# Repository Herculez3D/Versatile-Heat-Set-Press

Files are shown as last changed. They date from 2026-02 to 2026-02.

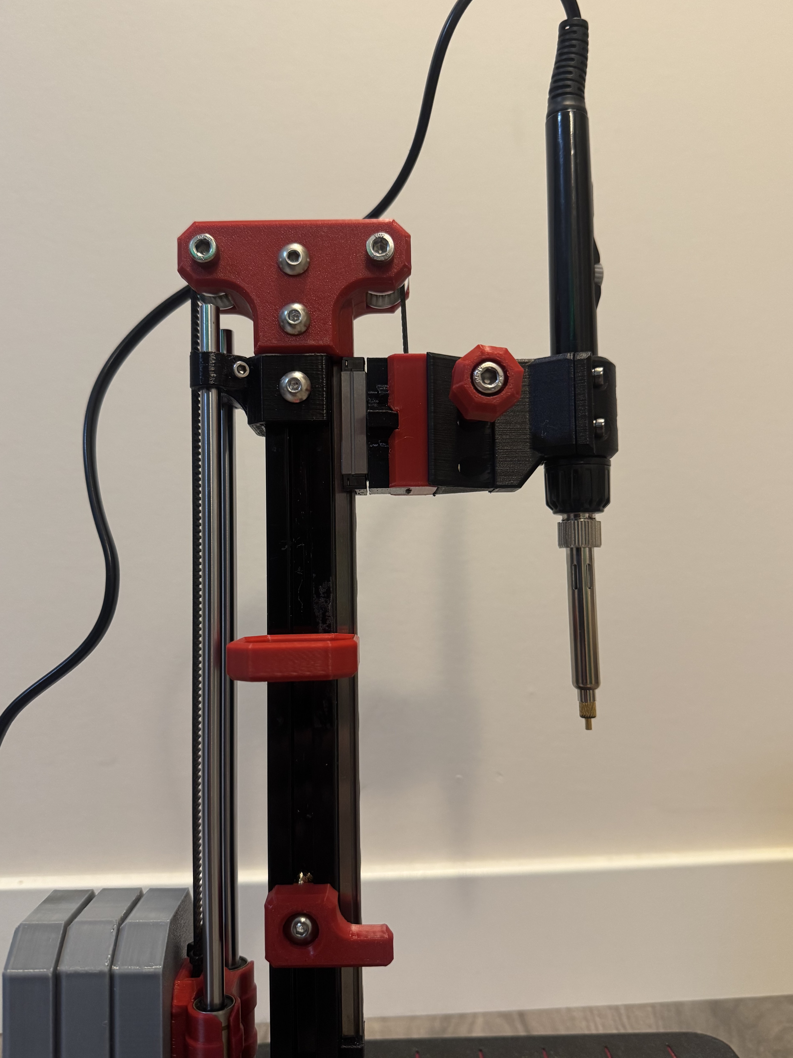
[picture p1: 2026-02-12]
Gallery/Upper Assembly.jpeg

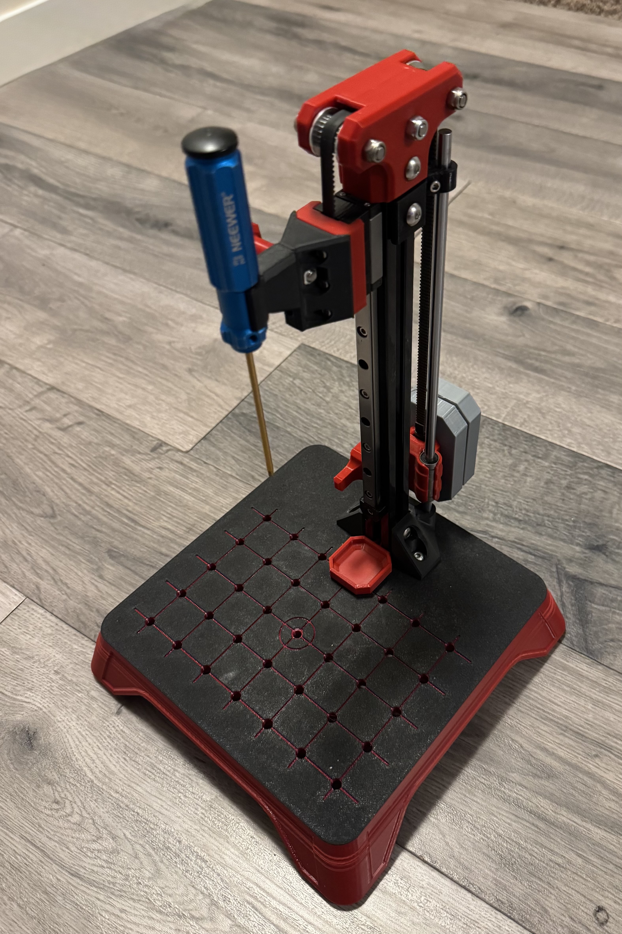
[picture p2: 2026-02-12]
Gallery/IMG_3691.jpeg

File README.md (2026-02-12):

# 🛠 Versatile Heat Seat Press (MGN9 Based)

A mostly 3D-printed, modular heat-set press built to live on your desk — and do more than just press inserts.

This started as “I need a better way to install heat-set inserts.”  
It turned into a small, milling-machine-inspired vertical platform that can grow into whatever you want it to be.

Want a heat-set press? Done.  
Want a mini drill press with a Dremel? Go for it.  
Want a precision vertical driver for starting threads? Easy.

The whole thing is designed to be **modular, hackable, and expandable.**

✅ Ender 3 compatible (235mm x 235mm build volume)

---

Main Cad

---

# 🚧 Project Status

This is an **active, evolving project.**

New parts and refinements are being added as I iterate.  
Assembly documentation is still in progress — for now, the Fusion 360 file is the best reference for hardware placement.

If you build one or improve something, I’d genuinely love to see it.

---

# 📢 Latest Updates (2026-02-11)

- Added new fixture parts and accessory components  
- Added a **Blank Tool Mount** for custom tooling  
- Fixed base alignment issue (moved third bolt to rear to ensure perpendicular extrusion alignment)  
- Added **Mini Tombstones** (hold ~10 Canadian dimes — currently testing)

---

# 🎯 Features

## 🧱 Fixture Plate Base
25mm grid layout with M5 mounting points allows you to:
- Design custom jigs  
- Add hard stops  
- Mount angle plates  
- Create repeatable setups  

Built to be expanded — not just used once.

---

## 🚂 MGN9 Linear Rail
- 200mm MGN9 rail  
- MGN9H carriage  

Smooth, rigid, controlled vertical motion.

---

## ⚖ Adjustable Counterweight System
Stackable “Tombstones” let you tune the feel of the press.

Fill options:
- Canadian nickels (15 tested per tombstone)
- Canadian dimes (mini version)
- Lead tire weights
- Steel stock
- Sand (pause print before top layers)
- Any dense material that fits

Weight cavity size must be smaller than:

`30mm (L) x 10mm (W) x 10mm (H)`

---

## 🔧 Modular Tooling System

- Blank tool mount included  
- Design your own tool posts  
- Mount rotary tools  
- Create specialty press heads  
- Build custom driver holders  

If you can model it, you can mount it.

---

# 📐 Specifications

- **Max Part Diameter:** 150mm  
- **Z Travel:** 155mm  
- **Bed Area:** 200mm x 150mm  
- **Printer Requirement:** 235mm x 235mm build plate  

---

# 🧰 Bill of Materials

## Frame & Motion
- 1x 300mm 2020 Aluminum Extrusion  
- 1x 200mm MGN9 Linear Rail  
- 1x MGN9H Linear Block  
- 2x 250mm 6mm Linear Rod  
- 2x LM6LUU Linear Bearings  
- 2x 20T 9mm GT2 Idlers (5mm ID)  
- ~400mm GT2 Belt (6mm or 9mm works)  
- 1x 3mm x 20mm Pin  

## M5 Hardware
- 2x M5 x45mm SHCS  
- 2x M5 x35mm SHCS (BHCS also works)  
- 14x M5 x10mm BHCS  
- 11x M5 T-Slot Nuts  
- 34x M5 Heat Set Inserts (7mm OD x 5mm long)  
- 4x M5 Hex Nuts  

## M3 Hardware
- 2x M3 x30mm SHCS  
- 10–20x M3 x15mm SHCS  
- 8x M3 x10mm SHCS  
- 11x M3 x8mm SHCS  
- 11x M3 T-Slot Nuts  
- 15–25x M3 Heat Set Inserts (Voron spec)  
- 2x M3 Square Nuts (2mm thick)  

## Misc
- Small zip ties  
- Heat-set insert tool  

---

# 🖨 Print Settings

## Standard Parts
- 0.2mm layer height  
- 0.4mm nozzle  
- 30% infill (Cubic recommended)  
- 3+ walls  
- 6+ top layers  
- 6+ bottom layers  
- No supports required  

## Recommended Materials
- PETG  
- ABS  
- ASA  
- TPU (for feet)  

PLA can be used for the base if necessary.

---

# 🧩 Print Notes

### Base
Large part — prone to warping.  
Ensure strong bed adhesion.

Optional: Manual filament swap at layer 3 for accent color.

### Tombstones
Use “Add Negative Part” in your slicer to create weight cavity.

Process:
1. Add cavity shape  
2. Add pause before bridge layer closes cavity  
3. Insert weights  
4. Resume print  

A Canadian nickel cavity model is included.

### Feet (x4)
Material: TPU  
- 2 walls  
- 3 bottom layers  
- 0 top layers  
- 25% hex infill  

### Tray (Optional)
Clips into extrusion.  
Convenient insert holder that stays out of the way.

---

# 🔩 Assembly

Assembly documentation coming soon.

For now:
- Reference the Fusion 360 file  
- Fasteners are shown in CAD  

---

# 🤝 Contributing

This project is meant to evolve.

If you:
- Design new tool mounts  
- Improve alignment  
- Create new fixture accessories  
- Optimize print strength  
- Expand travel  
- Improve documentation  

Open a PR or share your build.

---

# 💬 Final Notes

This press works great out of the box — but it was designed to grow with you.

Build it. Modify it. Improve it.

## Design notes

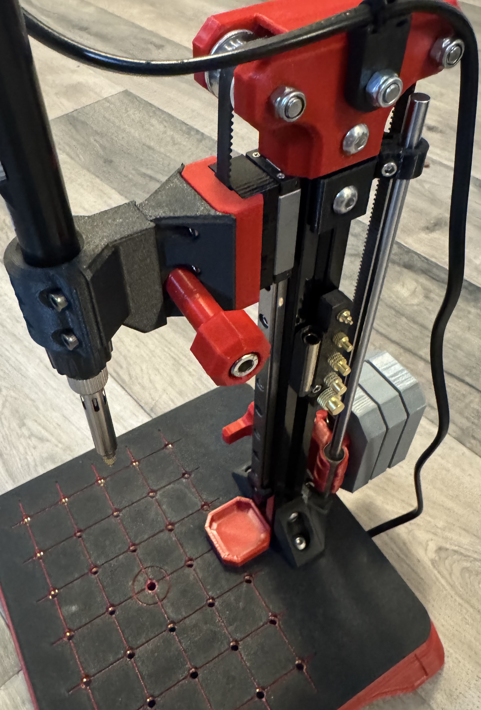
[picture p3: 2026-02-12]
Gallery/Right Side New.jpeg

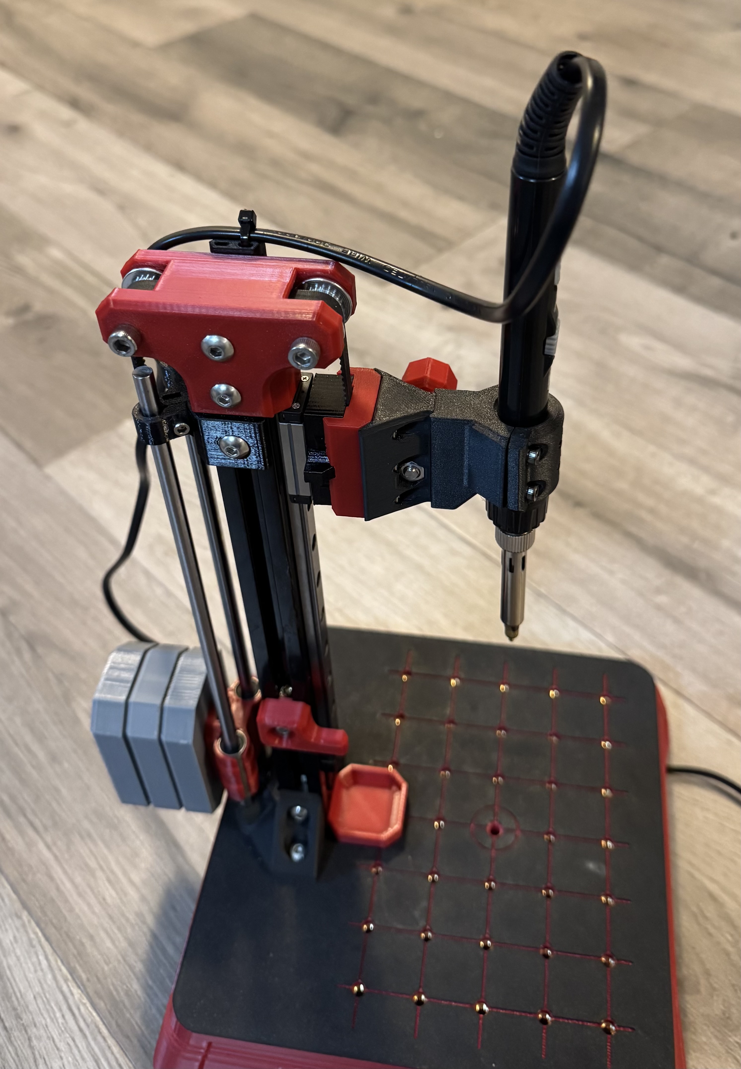
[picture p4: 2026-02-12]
Gallery/Left New.jpeg

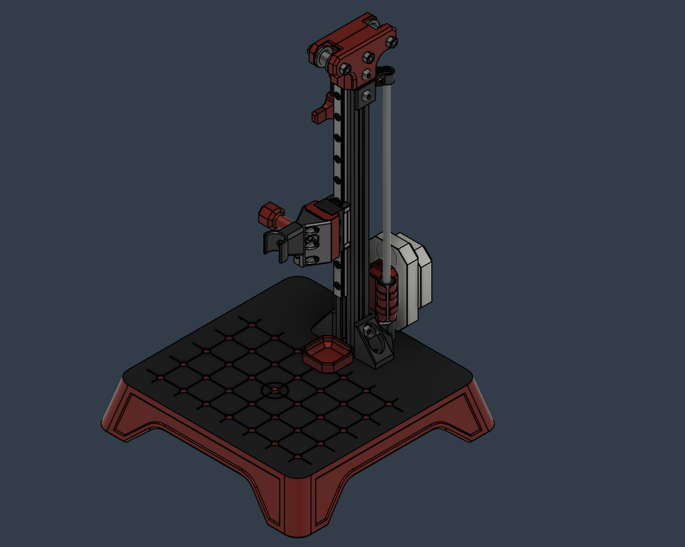
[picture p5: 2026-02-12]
Gallery/Screenshot (25).png

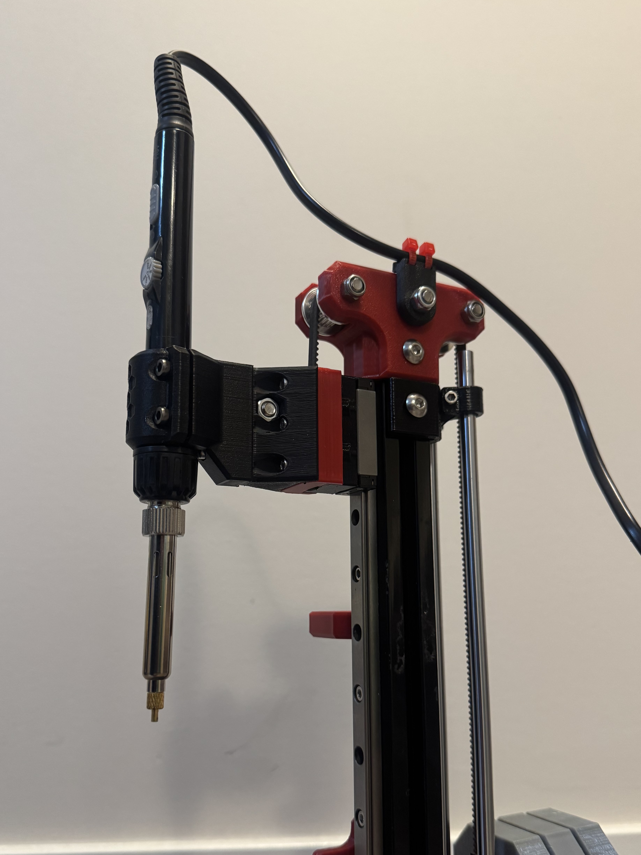
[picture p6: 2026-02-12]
Gallery/From under.jpeg

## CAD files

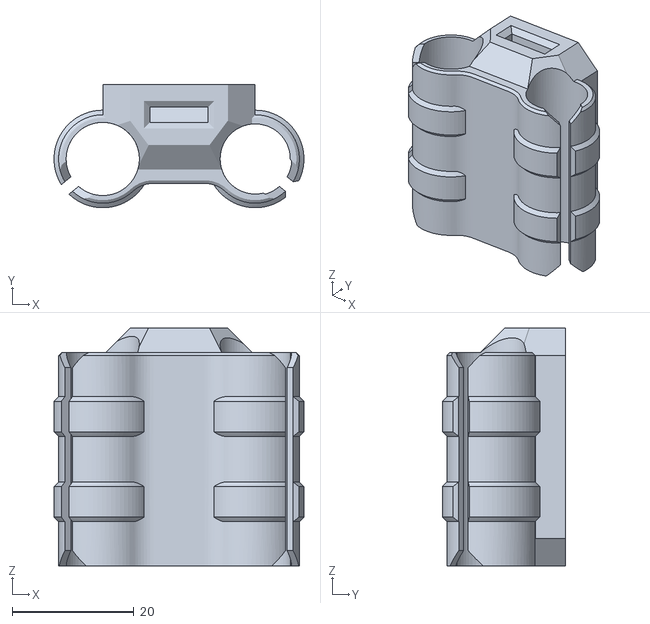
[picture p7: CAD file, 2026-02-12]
STL's/CounterWeight/Counterweight Carrier(a).stl
41.0 x 20.2 x 39.0

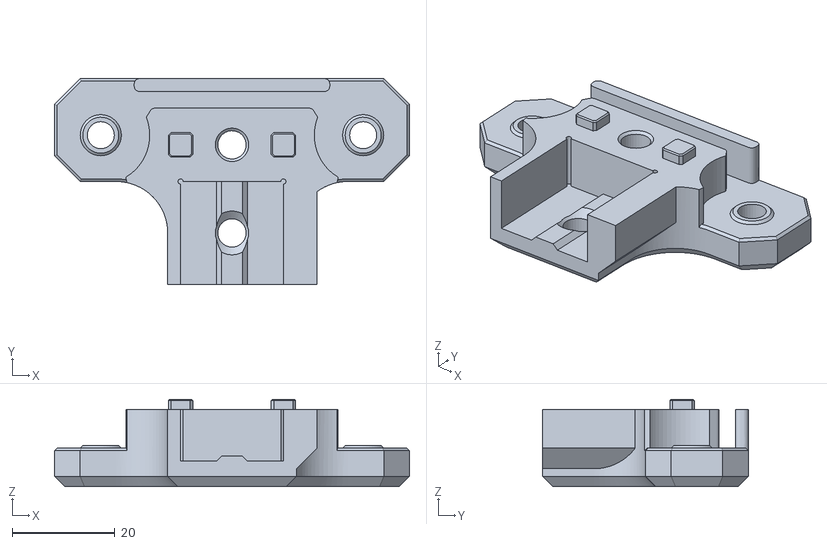
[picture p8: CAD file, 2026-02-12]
STL's/Frame/Pulley Block Right(a).stl
69.0 x 40.0 x 17.0

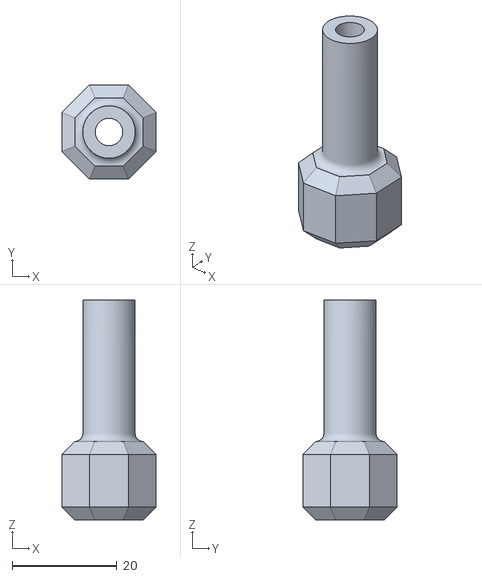
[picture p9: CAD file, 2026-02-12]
STL's/Tool Mounting/Knob(a).stl
18.0 x 18.0 x 42.0

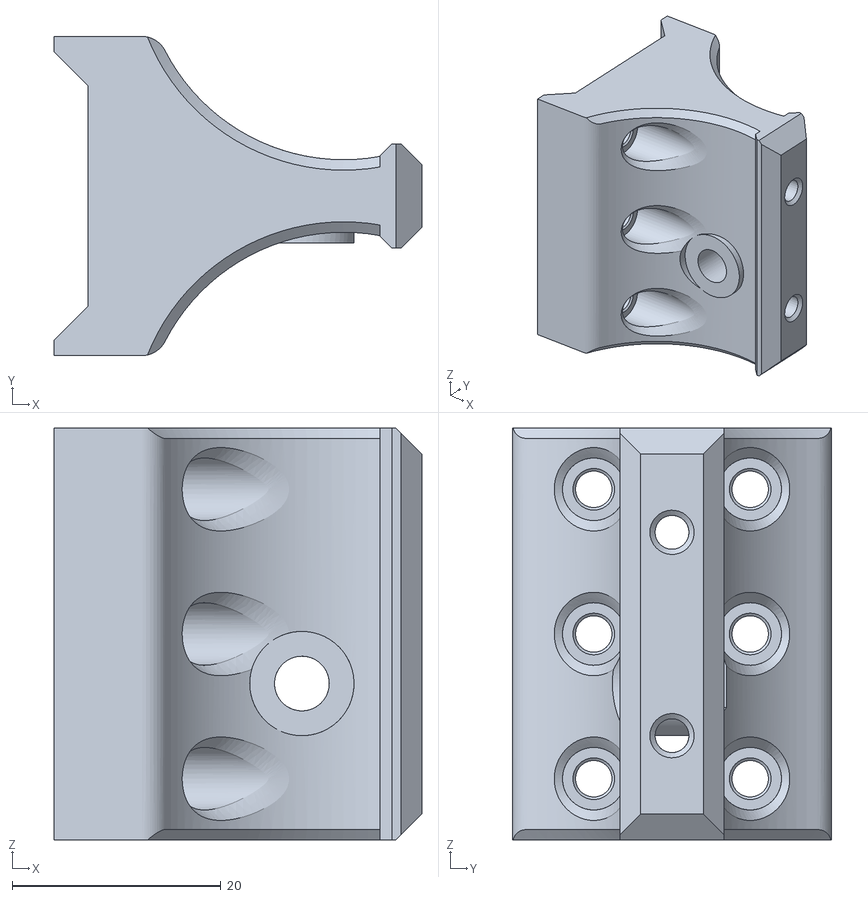
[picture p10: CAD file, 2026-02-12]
STL's/Tool Mounting/Long Tool Post/Tool Post Long.stl
35.2 x 30.6 x 39.5

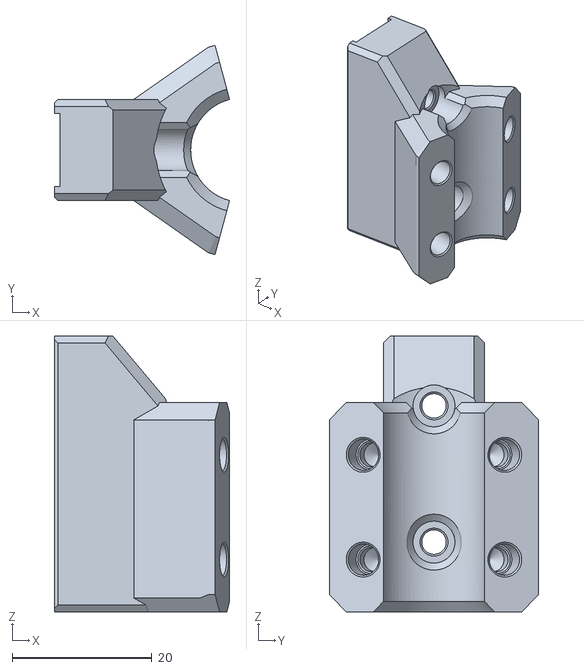
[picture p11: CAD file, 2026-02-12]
STL's/Tool Mounting/Short Tool Post/Amazon Heat Set Tool/Mount.stl
25.1 x 29.9 x 39.5

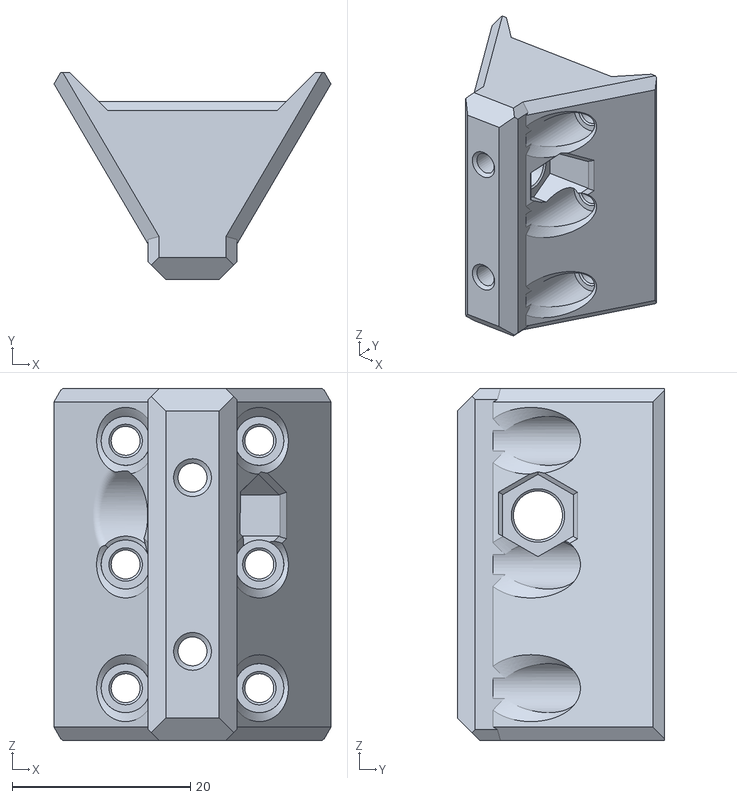
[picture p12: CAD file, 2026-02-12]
STL's/Tool Mounting/Short Tool Post/Tool Post Short.stl
31.1 x 23.3 x 39.5

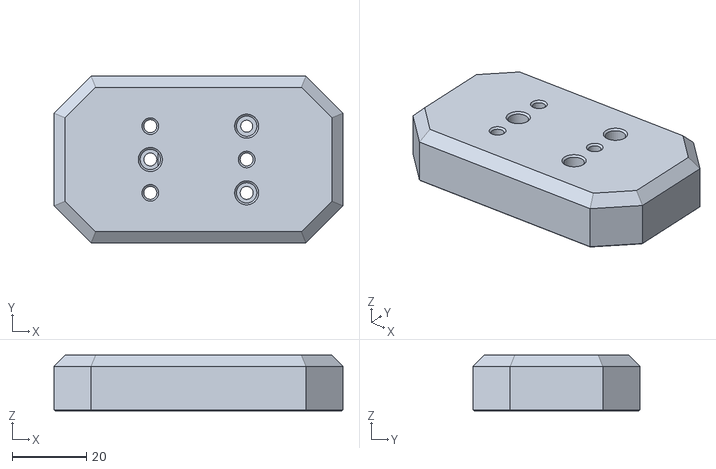
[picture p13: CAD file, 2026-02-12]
STL's/CounterWeight/Tombstone (Candian Nickel).stl
78.0 x 45.0 x 15.0

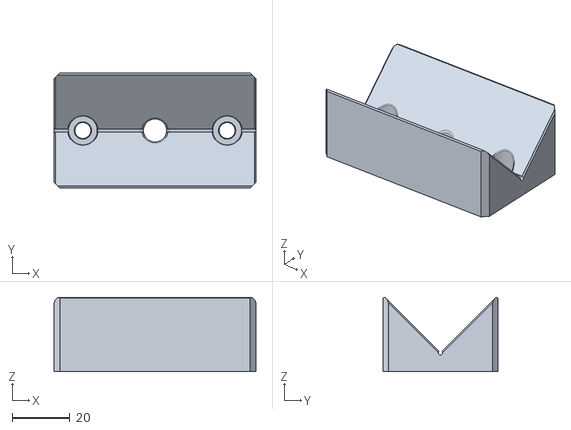
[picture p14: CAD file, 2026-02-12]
STL's/Fixtures/Vee Block.stl
70.0 x 40.0 x 25.8

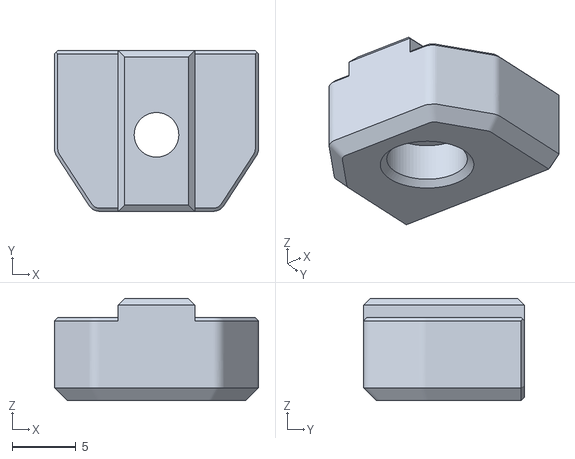
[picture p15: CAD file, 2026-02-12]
STL's/Frame/MGN9 Hard Stop.stl
16.0 x 12.6 x 8.00

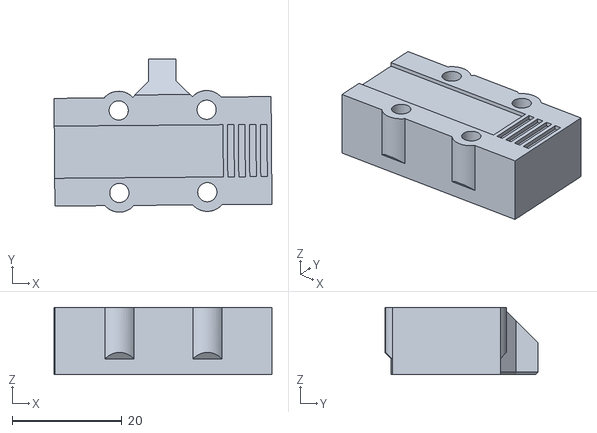
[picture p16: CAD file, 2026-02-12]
STL's/Tool Mounting/Belt Block.stl
39.7 x 27.9 x 12.3

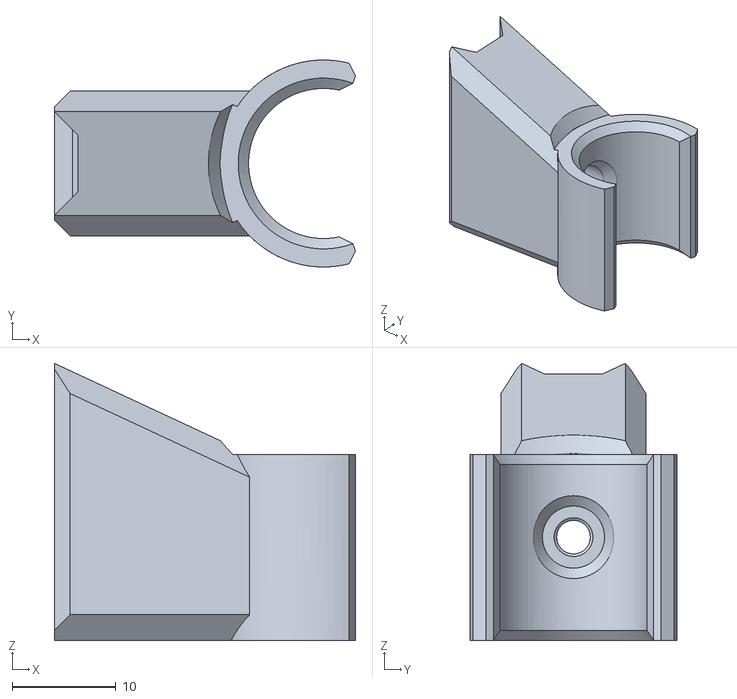
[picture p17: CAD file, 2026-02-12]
STL's/Tool Mounting/Short Tool Post/15mm Driver Holder.stl
29.1 x 20.0 x 26.8

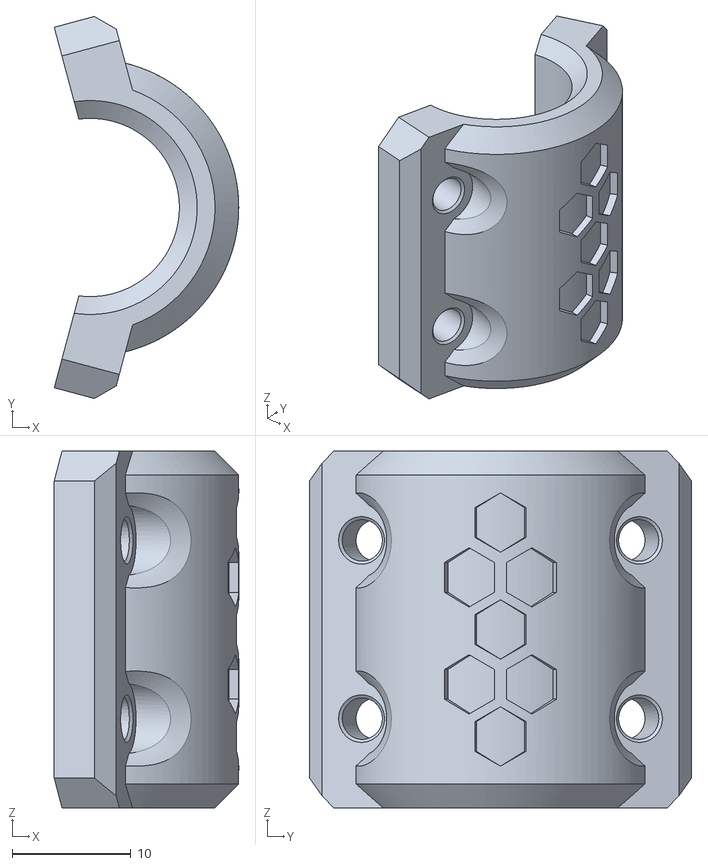
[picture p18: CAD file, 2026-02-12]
STL's/Tool Mounting/Short Tool Post/Amazon Heat Set Tool/Clamp.stl
15.5 x 32.1 x 30.0

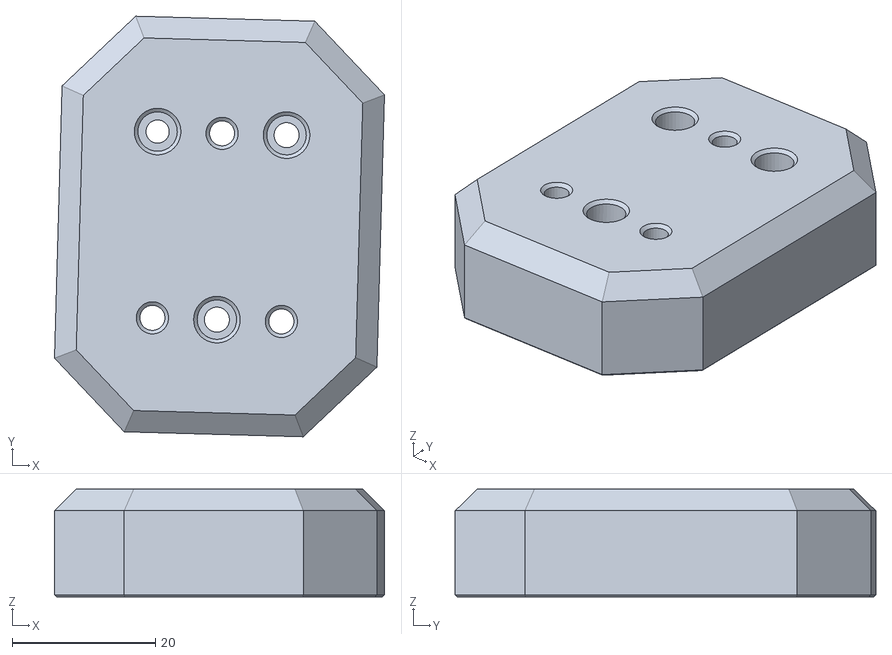
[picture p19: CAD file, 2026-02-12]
STL's/CounterWeight/MiniTombstone (Candian Dime).stl
46.0 x 58.7 x 15.0

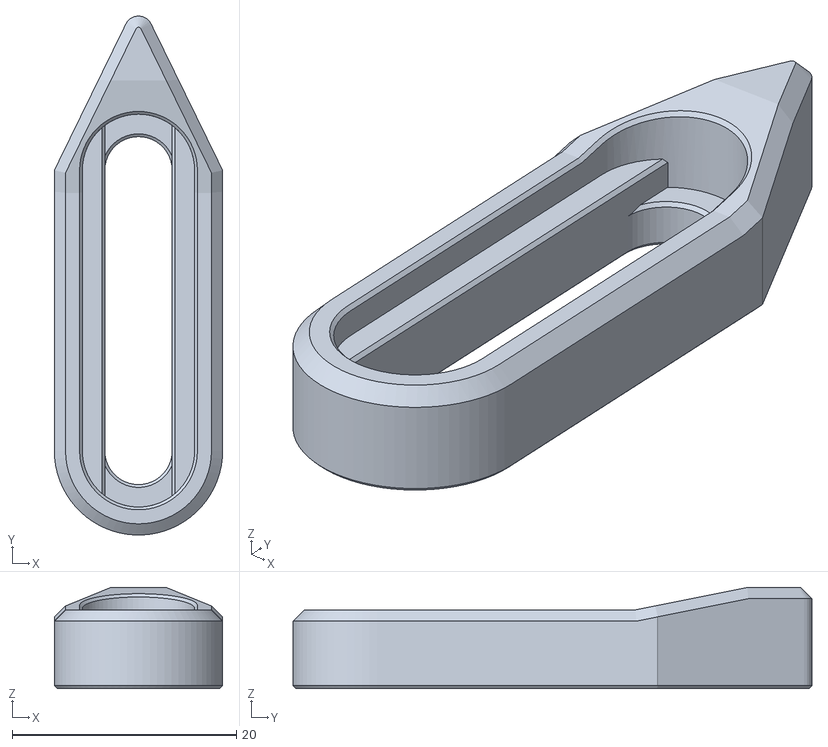
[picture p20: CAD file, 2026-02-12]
STL's/Fixtures/Pin Stop.stl
15.0 x 46.2 x 9.00

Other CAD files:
STL's/Frame/Bottom Brace.stl
STL's/Tool Mounting/Belt Clamp(a).stl
STL's/Tool Mounting/Short Tool Post/Amazon Heat Set Tool/Adapter Holder.stl
STL's/CounterWeight/Tombstone (solid).stl
STL's/Fixtures/Flat Stop.stl
STL's/Fixtures/Washer.stl
STL's/Frame/Adjustable Stop(a).stl
STL's/Frame/Base.stl
STL's/Frame/Cable Strain Relief.stl
STL's/Frame/Pulley Block Left(a).stl
STL's/Frame/Upper Bracket.stl
